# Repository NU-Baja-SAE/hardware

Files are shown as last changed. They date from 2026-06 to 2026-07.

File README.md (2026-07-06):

# NU Baja SAE — Hardware

KiCad schematics, PCB layouts, wiring harness designs, and BOM tooling for all NU Baja SAE electronics boards: the eCVT controller, the DAQ node, and the HUD node.

This guide assumes you have never used Git, GitHub, or KiCad before. Follow it top to bottom the first time; after that, skip to [Day-to-day workflow](#day-to-day-workflow).

## Table of contents

- [Glossary](#glossary)
- [One-time setup](#one-time-setup)
- [Getting the files onto your computer](#getting-the-files-onto-your-computer)
- [Opening a board in KiCad](#opening-a-board-in-kicad)
- [Day-to-day workflow](#day-to-day-workflow)
- [Structure](#structure)
- [Releases](#releases)
- [KiCad version](#kicad-version)

## Glossary

A few words you will see everywhere in this guide and on GitHub itself:

| Term | Meaning |
|---|---|
| Repository ("repo") | A folder of files (this one) tracked by Git, with full history of every change. |
| Git | The tool that tracks changes to files over time. Runs on your computer. |
| GitHub | The website that hosts a copy of the repo online so the team can share it. |
| Clone | Downloading a full copy of the repo (with its history) onto your computer. |
| Commit | A saved snapshot of your changes, with a short message describing what changed. |
| Push | Uploading your commits from your computer to GitHub. |
| Pull | Downloading other people's commits from GitHub to your computer. |
| Branch | An independent line of work, so you can make changes without touching `main` until they are ready. |
| Pull Request (PR) | A request to merge your branch into `main`, where others can review your changes before they land. |
| `main` | The default branch — the official, current state of the repo. |

## One-time setup

You only need to do this once per computer.

1. Create a GitHub account at [github.com](https://github.com) if you do not have one, and ask a team lead to add you to the `NU-Baja-SAE` organization so you have push access.
2. Install Git:
   - Windows: download and run the installer from [git-scm.com](https://git-scm.com/downloads). Default options are fine.
   - Mac: open Terminal and run `git --version` — macOS will offer to install it for you if it is missing.
3. Install GitHub Desktop (recommended if you are new to Git) from [desktop.github.com](https://desktop.github.com). It gives you a visual interface for the commit/push/pull steps below instead of typing commands. Everything in this guide can be done either with GitHub Desktop's buttons or with the `git` command line — both are described below.
4. Install KiCad — see [KiCad version](#kicad-version) below for which version to install. Download from [kicad.org/download](https://www.kicad.org/download/).
5. After cloning the repo (next section), add the shared parts library so connectors/ICs used across boards show up in KiCad — see [`libraries/README.md`](libraries/README.md).

## Getting the files onto your computer

This is called cloning the repo — it only needs to be done once per computer, after which you just "pull" updates.

Using GitHub Desktop:
1. Open GitHub Desktop and sign in with your GitHub account (File → Options → Accounts).
2. Click File → Clone Repository.
3. Choose the URL tab and paste: `https://github.com/NU-Baja-SAE/hardware`
4. Pick a local folder (e.g. `Documents/NU-Baja-SAE/hardware`) and click Clone.

Using the command line (Git Bash on Windows, Terminal on Mac):
```
git clone https://github.com/NU-Baja-SAE/hardware.git
cd hardware
```

Either way, you now have a folder called `hardware` on your computer containing everything in this repo.

## Opening a board in KiCad

Each board lives in its own folder under `boards/`, e.g. `boards/ecvt-controller/`. Inside that folder is a `.kicad_pro` file — this is the project file.

1. Open KiCad.
2. File → Open Project, then navigate to e.g. `hardware/boards/ecvt-controller/` and select the `.kicad_pro` file.
3. KiCad's project window shows the schematic (`.kicad_sch`) and PCB layout (`.kicad_pcb`) for that board — double-click either to open it in the schematic editor or PCB editor.
4. Make your edits and save (Ctrl+S / Cmd+S) as you normally would in KiCad. Saving only writes to your local copy of the files — it does not upload anything to GitHub. See the next section for how to share your changes.

If you are new to KiCad itself (not just this repo), the official [Getting Started guide](https://docs.kicad.org/) walks through schematic capture and PCB layout basics — worth a read before your first board edit.

## Day-to-day workflow

The general loop, every time you sit down to work on a board:

### 1. Pull the latest changes

Before you start editing, make sure you have everyone else's latest work, so you are not editing an outdated copy.

- GitHub Desktop: click Fetch origin, then Pull origin if it appears.
- Command line: `git pull`

### 2. Create a branch for your change

Do not edit `main` directly — work on a branch so your in-progress changes do not affect anyone else until they are reviewed.

- GitHub Desktop: click the branch dropdown (top middle) → New Branch. Name it something descriptive, e.g. `ecvt-add-current-sense`.
- Command line: `git checkout -b ecvt-add-current-sense`

### 3. Make your changes

Edit the KiCad files (schematic, PCB, etc.), or BOM/harness files, and save them as usual.

### 4. Commit your changes

A commit is a saved checkpoint with a message describing what you did. Commit often, in small logical chunks (e.g. "Add current sense resistor to eCVT controller" rather than one giant commit at the end).

- GitHub Desktop: the left panel lists every changed file. Check the ones you want to include, write a summary in the box at bottom-left, and click Commit to `<branch-name>`.
- Command line:
  ```
  git add boards/ecvt-controller/
  git commit -m "Add current sense resistor to eCVT controller"
  ```

### 5. Push your branch to GitHub

This uploads your commits so others (and CI, see below) can see them.

- GitHub Desktop: click Push origin.
- Command line: `git push -u origin ecvt-add-current-sense`

### 6. Open a Pull Request (PR)

A PR is how you propose merging your branch into `main`.

1. Go to [github.com/NU-Baja-SAE/hardware](https://github.com/NU-Baja-SAE/hardware) — GitHub usually shows a yellow banner offering to Compare & pull request for the branch you just pushed. Click it (or use GitHub Desktop's Create Pull Request button).
2. Write a short description of what changed and why.
3. Click Create pull request.
4. Automated checks (CI) will run against your PR — see `.github/workflows/ci.yml` for what gets checked (ERC/DRC, BOM diff, rendered schematic/PCB images, etc.). Wait for these to finish and fix anything they flag.
5. Ask a teammate to review. Once approved, click Merge pull request on GitHub.
6. Delete the branch (GitHub will prompt you) — its changes now live permanently in `main`.

### 7. Switch back to `main` and pull

- GitHub Desktop: switch the branch dropdown back to `main`, then Pull origin.
- Command line: `git checkout main && git pull`

You are back to a clean, up-to-date `main`, ready to start the loop again for your next change.

## Structure

```
hardware/
├── boards/
│   ├── ecvt-controller/   (.kicad_pro/.kicad_sch/.kicad_pcb + fab-outputs/ + README.md)
│   ├── daq-node/
│   └── hud-node/
├── harness/                # WireViz or WireLab YAML source + output/ (generated SVGs)
├── bom/
│   ├── consolidated-bom.csv
│   └── scripts/generate_bom.py
├── libraries/              # shared KiCad symbol/footprint libs
└── .github/workflows/
```

- `boards/<name>/` — one folder per physical board. Each contains its own KiCad project (`.kicad_pro`), schematic (`.kicad_sch`), PCB layout (`.kicad_pcb`), a `fab-outputs/` folder for generated gerbers/drill files/STEP models (not committed by hand — see below), and a short `README.md` describing the board.
- `harness/` — wiring harness definitions (WireViz/WireLab YAML), with rendered diagrams in `harness/output/`.
- `bom/` — the consolidated bill of materials across all boards (`consolidated-bom.csv`), generated automatically from the schematics by `bom/scripts/generate_bom.py`. Never edit the CSV by hand. If you change a schematic, run `python3 bom/scripts/generate_bom.py` and commit the updated CSV alongside your change — CI fails the PR if the committed CSV is out of date (and auto-regenerates it on direct pushes to `main` as a safety net).
- `libraries/` — shared KiCad symbol and footprint libraries used by more than one board, so parts stay consistent across designs.
- `.github/workflows/` — CI configuration; this is what automatically checks your PRs (see step 6 above).

Do not manually commit fab outputs (gerbers, drill files, `.step` files) — these are generated from the KiCad source files and are gitignored. CI regenerates them automatically on each PR.

## Releases

Board releases are tagged at the point gerbers are sent to fab, e.g. `ecvt-controller-v1.2`, with a one-line changelog per board.

## KiCad version

All board files must be authored/saved in the same KiCad version to avoid spurious diffs from format upgrades. Current standard version: **KiCad 9.0** — this is also the version CI runs (the `kicad/kicad:9.0` image in `.github/workflows/ci.yml`), so files saved in a newer major version will fail CI until both are bumped together.

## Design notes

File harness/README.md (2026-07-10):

# harness

The car's off-board wiring diagram — the wires that run **between** boards,
not the wiring internal to any one board. It is generated from the KiCad
board schematics on every push, so it can't drift out of sync with the boards.

## What's here

| Path | What it is |
|---|---|
| `car.yaml` | **Hand-maintained backbone.** The only file you edit by hand: it declares the battery/master-switch spine, the inter-board wires (CAN bus, power), and any junction boxes. It `includes:` the generated per-board connectors. |
| `generated/<board>.yaml` | **Build artifacts — never hand-edit.** One file per board listing that board's off-board connectors, extracted from its schematic. |
| `output/car.svg` | The rendered whole-car diagram. Regenerated + committed by CI. |
| `scripts/extract_connectors.py` | Extracts off-board connectors from each board's KiCad schematic (see `scripts/README.md`). |
| `scripts/test_pipeline.py` | Smoke test: extractor → build → idempotency. |
| `wirelab/` | Vendored copy of the YAML→SVG harness renderer (Wirelab). Build path needs `pydantic` + `PyYAML` (see `wirelab/requirements.txt`). |

## The pipeline

```
boards/<board>/*.kicad_sch
   │  extract_connectors.py  (kicad-cli netlist; keeps TE 917xxx + Molex 153110xx connectors)
   ▼
harness/generated/<board>.yaml
   │  included by
   ▼
harness/car.yaml  (hand-maintained backbone: battery, switch, inter-board wires)
   │  wirelab/cli.py build
   ▼
harness/output/car.svg
```

## Regenerate locally

Needs `kicad-cli` (KiCad 9) on PATH and the renderer's deps installed:

```
pip install -r harness/wirelab/requirements.txt
python3 harness/scripts/extract_connectors.py
python3 harness/wirelab/cli.py build harness/car.yaml -o harness/output/car.svg
```

Or just run the smoke test, which does the extract + build:

```
python3 harness/scripts/test_pipeline.py
```

## CI

The `harness-render` job (`.github/workflows/ci.yml`) runs in the
`kicad/kicad:9.0` container. On a **PR** it fails if the committed
`generated/*.yaml` or `output/car.svg` are stale (`extract_connectors.py
--check` + an SVG diff). On a **push to `main`** it regenerates and
auto-commits them (`[skip ci]`), the same safety-net pattern the consolidated
BOM job uses. So: change a board → push → the diagram updates itself.

Because CI rewrites `generated/*.yaml` and `output/car.svg` on every push to
`main`, their committed bytes are a moving target and two branches will almost
always differ there. To stop that from producing merge conflicts, those paths
are marked `merge=ours` in `.gitattributes` (git keeps one side instead of
conflicting; the next CI run regenerates the canonical copy). GitHub's merge
button honors this server-side. If you **merge or rebase locally**, register
the driver once so the attribute takes effect:

```
git config merge.ours.driver true
```

## Adding an inter-board wire / junction box

Edit `car.yaml`. Reference a board connector by its include alias and refdes,
e.g. `ecvt.J6.CANH`. Cross-board wires and the battery/switch spine live only
here; per-board connector pins come from `generated/` and update when the
board changes.

## Auxiliary boards & repeated (instanced) boards

Small aux boards (wheel/eCVT hall sensors, fuel sensor) follow the same
pattern as the big three: **one file per unique design**, instanced in
`car.yaml`.

- **A board that appears more than once on the car** (e.g. four identical
  wheel hall sensors) is still just ONE `generated/*.yaml`. Import it under
  several aliases in `car.yaml`'s `includes:` — `wheel_fl:`, `wheel_fr:`, … all
  pointing at `generated/wheel-hall.yaml`. Each alias becomes a separate copy
  of the connector in the diagram. The renderer namespaces each component's
  layout **zone by its include alias**, so every instance gets its own column
  (see `_resolve_includes` in `wirelab/parser.py`). Wire each instance
  independently, e.g. `daq.J7.LEFT_HALL -> wheel_fl.J1.HALL_OUT`.

- **A real KiCad board** goes in `boards/<name>/` and its `generated/<name>.yaml`
  is produced by `extract_connectors.py` like any other board.

- **A placeholder board** (design not drawn yet) can be a hand-written
  `generated/<name>.yaml` with a `# HAND-WRITTEN PLACEHOLDER` header. Because
  the extractor only writes/`--check`s files for folders that exist under
  `boards/`, a placeholder with no matching board folder is left untouched by
  CI. When you later add `boards/<name>/`, the extractor regenerates that file
  and it becomes a normal build artifact — the hand file is transparently
  replaced. (Keep the placeholder's connectors/pins matching the intended
  design so the diagram stays truthful until the real board lands.)

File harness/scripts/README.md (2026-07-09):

# harness/scripts

## `extract_connectors.py`

Generates `harness/generated/<board>.yaml` — one file per board describing
that board's **off-board** connectors (the pins whose wires leave the board
and become part of the car harness). Board-internal nets are ignored.

It runs `kicad-cli sch export netlist` on each board's root schematic, keeps
only the harness connector families (TE 917xxx, Molex 15311026/15311046), and
writes a pin-per-connector-pin YAML with each pin named by the net on it.

```
python3 harness/scripts/extract_connectors.py          # regenerate generated/*.yaml
python3 harness/scripts/extract_connectors.py --check   # exit 1 if any file is stale (CI)
```

Requires `kicad-cli` (KiCad 9) on PATH. Symbols resolve from each schematic's
embedded cache, so no library table / `BAJA_LIB` env var is needed — it runs
the same on a laptop and in the CI `kicad/kicad:9.0` container.

### Files under `harness/generated/` are BUILD ARTIFACTS

Never hand-edit them. To change a connector, edit the board schematic and
regenerate. CI runs `--check` on every PR; if it fails, regenerate and commit.

### The pipeline

```
boards/<board>/*.kicad_sch
        │  extract_connectors.py (kicad-cli netlist)
        ▼
harness/generated/<board>.yaml        (one connector component per J-ref)
        │  included by
        ▼
harness/car.yaml   (hand-maintained backbone: joins boards, junction boxes,
        │           inter-board wires)
        ▼  wireviz_alternative build
harness/output/car.svg                (the whole-car off-board wiring diagram)
```

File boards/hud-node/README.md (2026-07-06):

# hud-node

KiCad project for the HUD node board. Add `.kicad_pro`/`.kicad_sch`/`.kicad_pcb` files here, with generated fab outputs under `fab-outputs/` (gitignored).

<!-- CI trigger test -->

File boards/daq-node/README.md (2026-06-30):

# daq-node

KiCad project for the DAQ node board. Add `.kicad_pro`/`.kicad_sch`/`.kicad_pcb` files here, with generated fab outputs under `fab-outputs/` (gitignored).

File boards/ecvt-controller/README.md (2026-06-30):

# ecvt-controller

KiCad project for the eCVT controller board. Add `.kicad_pro`/`.kicad_sch`/`.kicad_pcb` files here, with generated fab outputs under `fab-outputs/` (gitignored).

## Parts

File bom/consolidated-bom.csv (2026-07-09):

part_number | description | manufacturer | quantity | board | notes
0.1 µF 0603 | Unpolarized capacitor |  | 1 | daq-node | C11
0.1 µF 0603 | Unpolarized capacitor, small symbol |  | 1 | daq-node | C5
0.1 µF 0805 | Unpolarized capacitor |  | 3 | daq-node | C2 C4 C6
15311026 |  |  | 1 | daq-node | J5
1k 0603 | Resistor |  | 1 | daq-node | R3
220 pF 0603 | Unpolarized capacitor |  | 2 | daq-node | C19 C20
4.7µF 0603 | Unpolarized capacitor |  | 3 | daq-node | C1 C3 C12
5V | Zener diode |  | 1 | daq-node | D2
917780-1 |  |  | 1 | daq-node | J8
917781-1 |  |  | 1 | daq-node | J4
917783-1 |  | TE | 1 | daq-node | J7
917784-1 |  |  | 1 | daq-node | J1
ACT45B-101-2P-TL003 |  |  | 1 | daq-node | U5
Conn_01x19_Socket | Generic connector, single row, 01x19, script generated |  | 2 | daq-node | J11 J12
DF2S5M4CTL3FCT-ND | Zener diode |  | 4 | daq-node | D3 D4 D5 D6
DM3CS-SF |  | Hirose | 1 | daq-node | J6
Fuse 0603 | Fuse |  | 1 | daq-node | F1
Q_PMOS_DGS | P-MOSFET transistor, drain/gate/source |  | 1 | daq-node | Q1
SMAJ26A | 400W unidirectional Transient Voltage Suppressor, 26.0Vr, SMA(DO-214AC) |  | 1 | daq-node | D1
TJA1051T-3 | High-Speed CAN Transceiver, separate VIO, silent mode, SOIC-8 |  | 1 | daq-node | U2
TPD2EUSB30 | 2-Channel ESD Protection for Super-Speed USB 3.0 Interface, DRT-3 |  | 1 | daq-node | U4
TSR_1-2450 | 1A step-down regulator module, fixed 5V output voltage, 5-36V input voltage, -40°C to +85°C temperature range, TO-220 compatible LM78xx replacement |  | 1 | daq-node | U3
0.01µF 0603 | Unpolarized capacitor, small symbol |  | 3 | ecvt-controller | C1 C3 C5
0.1 µF 0603 | Unpolarized capacitor |  | 6 | ecvt-controller | C10 C11 C13 C15 C17 C18
0.1 µF 0603 | Unpolarized capacitor, small symbol |  | 3 | ecvt-controller | C6 C8 C9
100µF | Polarized capacitor, small symbol |  | 1 | ecvt-controller | C2
10k 0603 | Resistor |  | 2 | ecvt-controller | R6 R7
10kΩ 0603 | Resistor, small US symbol |  | 2 | ecvt-controller | R1 R2
15311026 |  |  | 1 | ecvt-controller | J4
15311046 |  |  | 1 | ecvt-controller | J2
1k 0603 | Resistor |  | 1 | ecvt-controller | R3
1µF 0603 | Unpolarized capacitor, small symbol |  | 2 | ecvt-controller | C4 C7
220 pF 0603 | Unpolarized capacitor |  | 2 | ecvt-controller | C19 C20
4.7µF 0603 | Unpolarized capacitor |  | 3 | ecvt-controller | C12 C14 C16
5V | Zener diode |  | 1 | ecvt-controller | D4
60 1206 | Resistor |  | 2 | ecvt-controller | R4 R5
917780-1 |  |  | 1 | ecvt-controller | J6
917781-1 |  |  | 1 | ecvt-controller | J10
917782-1 |  |  | 1 | ecvt-controller | J1
917784-1 |  |  | 1 | ecvt-controller | J3
917786-1 |  |  | 1 | ecvt-controller | J5
ACT45B-101-2P-TL003 |  |  | 1 | ecvt-controller | U5
Conn_01x19_Socket | Generic connector, single row, 01x19, script generated |  | 2 | ecvt-controller | J8 J9
ESD3V3AP-TP |  |  | 3 | ecvt-controller | U2 U6 U7
Fuse 0603 | Fuse |  | 1 | ecvt-controller | F1
LED | Light emitting diode |  | 2 | ecvt-controller | D2 D6
Q_PMOS_DGS | P-MOSFET transistor, drain/gate/source |  | 1 | ecvt-controller | Q1
S23LC03 |  |  | 1 | ecvt-controller | U8
SMAJ26A | 400W unidirectional Transient Voltage Suppressor, 26.0Vr, SMA(DO-214AC) |  | 1 | ecvt-controller | D5
TI DRV8462DDVR | 65 V, 5-10 A Stepper Motor Driver for High Efficiency and Noiseless Operation |  | 1 | ecvt-controller | U1
TJA1051T-3 | High-Speed CAN Transceiver, separate VIO, silent mode, SOIC-8 |  | 1 | ecvt-controller | U4
TSR_1-2450 | 1A step-down regulator module, fixed 5V output voltage, 5-36V input voltage, -40°C to +85°C temperature range, TO-220 compatible LM78xx replacement |  | 1 | ecvt-controller | U3
.01u 0805 | Unpolarized capacitor |  | 2 | hud-node | C1 C2
.1uF 0603 | Unpolarized capacitor |  | 1 | hud-node | C6
.1uf 0805 | Unpolarized capacitor |  | 1 | hud-node | C7
0603 Fuse 0603 | Fuse |  | 1 | hud-node | F1
100 0603 | Resistor |  | 1 | hud-node | R4
1k 0603 | Resistor |  | 1 | hud-node | R3
220p 0603 | Unpolarized capacitor |  | 2 | hud-node | C4 C5
4.7u 0603 | Polarized capacitor |  | 1 | hud-node | C3
5V | Zener diode |  | 1 | hud-node | D1
60 1206 | Resistor |  | 2 | hud-node | R1 R2
917780-1 |  |  | 2 | hud-node | J3 J4
917781-1 |  |  | 1 | hud-node | J6
ACT45B-101-2P-TL003 |  |  | 1 | hud-node | U3
Conn_01x04 | Generic connector, single row, 01x04, script generated (kicad-library-utils/schlib/autogen/connector/) |  | 1 | hud-node | J5
Conn_01x19_Socket | Generic connector, single row, 01x19, script generated |  | 2 | hud-node | J1 J2
Q_PMOS_DGS | P-MOSFET transistor, drain/gate/source |  | 1 | hud-node | Q1
R_Potentiometer | Potentiometer |  | 1 | hud-node | RV1
SMAJ26A | 400W unidirectional Transient Voltage Suppressor, 26.0Vr, SMA(DO-214AC) |  | 1 | hud-node | D2
TJA1051T-3 | High-Speed CAN Transceiver, separate VIO, silent mode, SOIC-8 |  | 1 | hud-node | U2
TPD2EUSB30 | 2-Channel ESD Protection for Super-Speed USB 3.0 Interface, DRT-3 |  | 1 | hud-node | U5
TSR_1-2450 | 1A step-down regulator module, fixed 5V output voltage, 5-36V input voltage, -40°C to +85°C temperature range, TO-220 compatible LM78xx replacement |  | 1 | hud-node | U1
~ | 4.7 inch 240x128 Dots Graphic LCD Module |  | 1 | hud-node | U4

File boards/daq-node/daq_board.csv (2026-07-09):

Reference | Qty | Value | DNP | Exclude from BOM | Exclude from Board | Footprint | Datasheet
C1,C3 | 2 | 4.7µF |  |  |  | Capacitor_SMD:C_0603_1608Metric_Pad1.08x0.95mm_HandSolder | ~
C2,C4,C6 | 3 | 0.1 µF |  |  |  | Capacitor_SMD:C_0805_2012Metric_Pad1.18x1.45mm_HandSolder | ~
C5,C18 | 2 | 0.1 µF |  |  |  | Capacitor_SMD:C_0603_1608Metric_Pad1.08x0.95mm_HandSolder | ~
C19,C20 | 2 | 220 pF |  |  |  | Capacitor_SMD:C_0603_1608Metric_Pad1.08x0.95mm_HandSolder | ~
D1 | 1 | SMAJ26A |  |  |  | Diode_SMD:D_SMA | https://www.littelfuse.com/media?itemid=75e32973-b177-4ee3-a0ff-cedaf1abdb93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
D2 | 1 | 5V |  |  |  | Diode_SMD:D_SMA | ~
J1,J2,J3,J4,J5,J6,J7 | 7 | 917781-1 |  |  |  | Connector_1x3:CON3_1X3_P100 | https://www.te.com/commerce/DocumentDelivery/DDEController?Action=srchrtrv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
J8,J9 | 2 | 917780-1 |  |  |  | Connector_1x2:CON2_1X2_P100 | https://www.te.com/commerce/DocumentDelivery/DDEController?Action=srchrtrv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
J10 | 1 | Conn_01x09_Socket |  |  |  | Connector_PinHeader_2.54mm:PinHeader_1x09_P2.54mm_Vertical | ~
J11,J12 | 2 | Conn_01x19_Socket |  |  |  | Connector_PinHeader_2.54mm:PinHeader_1x19_P2.54mm_Vertical | ~
Q1 | 1 | Q_PMOS_DGS |  |  |  | Package_TO_SOT_SMD:SOT-23-3 | ~
R1,R2 | 2 | 60 |  |  |  | Resistor_SMD:R_0603_1608Metric_Pad0.98x0.95mm_HandSolder | ~
R3 | 1 | 1k |  |  |  | Resistor_SMD:R_0603_1608Metric_Pad0.98x0.95mm_HandSolder | ~
U2 | 1 | TJA1051T-3 |  |  |  | Package_SO:SOIC-8_3.9x4.9mm_P1.27mm | http://www.nxp.com/docs/en/data-sheet/TJA1051.pdf
U3 | 1 | TSR_1-2450 |  |  |  | Converter_DCDC:Converter_DCDC_TRACO_TSR-1_THT | http://www.tracopower.com/products/tsr1.pdf
U4 | 1 | TPD2EUSB30 |  |  |  | Package_TO_SOT_SMD:Texas_DRT-3 | http://www.ti.com/lit/ds/symlink/tpd2eusb30a.pdf
U5 | 1 | ACT45B-101-2P-TL003 |  |  |  | baja_footprint_library:ACT45B-101-2P-TL003

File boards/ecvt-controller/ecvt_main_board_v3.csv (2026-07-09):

Reference | Qty | Value | DNP | Exclude from BOM | Exclude from Board | Footprint | Datasheet
C1,C3,C5 | 3 | 0.01µF |  |  |  | Capacitor_SMD:C_0603_1608Metric_Pad1.08x0.95mm_HandSolder | ~
C2 | 1 | 100µF |  |  |  | Capacitor_SMD:CP_Elec_10x10.5 | ~
C4,C7 | 2 | 1µF |  |  |  | Capacitor_SMD:C_0603_1608Metric_Pad1.08x0.95mm_HandSolder | ~
C6,C8,C9 | 3 | 0.1 µF |  |  |  | Capacitor_SMD:C_0603_1608Metric_Pad1.08x0.95mm_HandSolder | ~
C10,C11,C13,C15,C17,C18 | 6 | 0.1 µF |  |  |  | Capacitor_SMD:C_0805_2012Metric_Pad1.18x1.45mm_HandSolder | ~
C12,C14,C16 | 3 | 4.7µF |  |  |  | Capacitor_SMD:C_0603_1608Metric_Pad1.08x0.95mm_HandSolder | ~
C19,C20 | 2 | 220 pF |  |  |  | Capacitor_SMD:C_0603_1608Metric_Pad1.08x0.95mm_HandSolder | ~
D1,D3 | 2 | DF2S5M4CTL3FCT-ND |  |  |  | Diode_SMD:D_SOD-882 | ~
D2,D6 | 2 | LED |  |  |  | LED_SMD:LED_Luminus_MP-3030-1100_3.0x3.0mm | ~
D4 | 1 | 5V |  |  |  | Diode_SMD:D_SMA | ~
D5 | 1 | SMAJ26A |  |  |  | Diode_SMD:D_SMA | https://www.littelfuse.com/media?itemid=75e32973-b177-4ee3-a0ff-cedaf1abdb93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
F1 | 1 | Fuse |  |  |  | Fuse:Fuse_0603_1608Metric_Pad1.05x0.95mm_HandSolder | ~
H1,H2,H3,H4 | 4 | MountingHole |  | Excluded from BOM |  | MountingHole:MountingHole_3.2mm_M3 | ~
J1 | 1 | 917782-1 |  |  |  | baja_footprint_library:TE-Connectivity_917782 | https://www.te.com/commerce/DocumentDelivery/DDEController?Action=srchrtrv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
J2 | 1 | 15311046 |  |  |  | baja_footprint_library:MOLEX_15311046 | https://www.molex.com/en-us/products/part-detail-pdf/15311046?display=pdf
J3 | 1 | 917791-1 |  |  |  | baja_footprint_library:TE-Connectivity_917791
J4 | 1 | 15311026 |  |  |  | baja_footprint_library:MOLEX_15311026 | https://www.molex.com/en-us/products/part-detail-pdf/15311026?display=pdf
J6 | 1 | 917780-1 |  |  |  | baja_footprint_library:TE-Connectivity_ 917780 | https://www.te.com/commerce/DocumentDelivery/DDEController?Action=srchrtrv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
J8,J9 | 2 | Conn_01x19_Socket |  |  |  | Connector_PinSocket_2.54mm:PinSocket_1x19_P2.54mm_Vertical | ~
J10 | 1 | 917781-1 |  |  |  | baja_footprint_library:TE-Connectivity_917781 | https://www.te.com/commerce/DocumentDelivery/DDEController?Action=srchrtrv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
Q1 | 1 | Q_PMOS_DGS |  |  |  | Package_TO_SOT_SMD:SOT-23-3 | ~
R1,R2 | 2 | 10kΩ |  |  |  | Resistor_SMD:R_0603_1608Metric_Pad0.98x0.95mm_HandSolder | ~
R3 | 1 | 1k |  |  |  | Resistor_SMD:R_0603_1608Metric_Pad0.98x0.95mm_HandSolder | ~
R4,R5 | 2 | 60 |  |  |  | Resistor_SMD:R_0603_1608Metric_Pad0.98x0.95mm_HandSolder | ~
R6,R7 | 2 | 100k |  |  |  | Resistor_SMD:R_0603_1608Metric_Pad0.98x0.95mm_HandSolder | ~
U1 | 1 | TI DRV8462DDVR |  |  |  | Package_SO:HTSSOP-44_6.1x14mm_P0.635mm_TopEP4.14x7.01mm | kicad-embed://Motor Driver 10A (drv8462).pdf
U2,U6 | 2 | TPD2EUSB30 |  |  |  | Package_TO_SOT_SMD:Texas_DRT-3 | http://www.ti.com/lit/ds/symlink/tpd2eusb30a.pdf
U3 | 1 | TSR_1-2450 |  |  |  | Converter_DCDC:Converter_DCDC_TRACO_TSR-1_THT | http://www.tracopower.com/products/tsr1.pdf
U4 | 1 | TJA1051T-3 |  |  |  | Package_SO:SOIC-8_3.9x4.9mm_P1.27mm | http://www.nxp.com/docs/en/data-sheet/TJA1051.pdf
U5 | 1 | ACT45B-101-2P-TL003 |  |  |  | baja_footprint_library:ACT45B-101-2P-TL003

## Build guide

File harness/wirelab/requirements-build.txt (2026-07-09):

# Dependencies for the BUILD path only (extract + build the diagram in CI).
# The interactive `serve` editor additionally needs ruamel.yaml (see
# requirements.txt), but CI never runs the editor.
pydantic>=2
PyYAML>=6

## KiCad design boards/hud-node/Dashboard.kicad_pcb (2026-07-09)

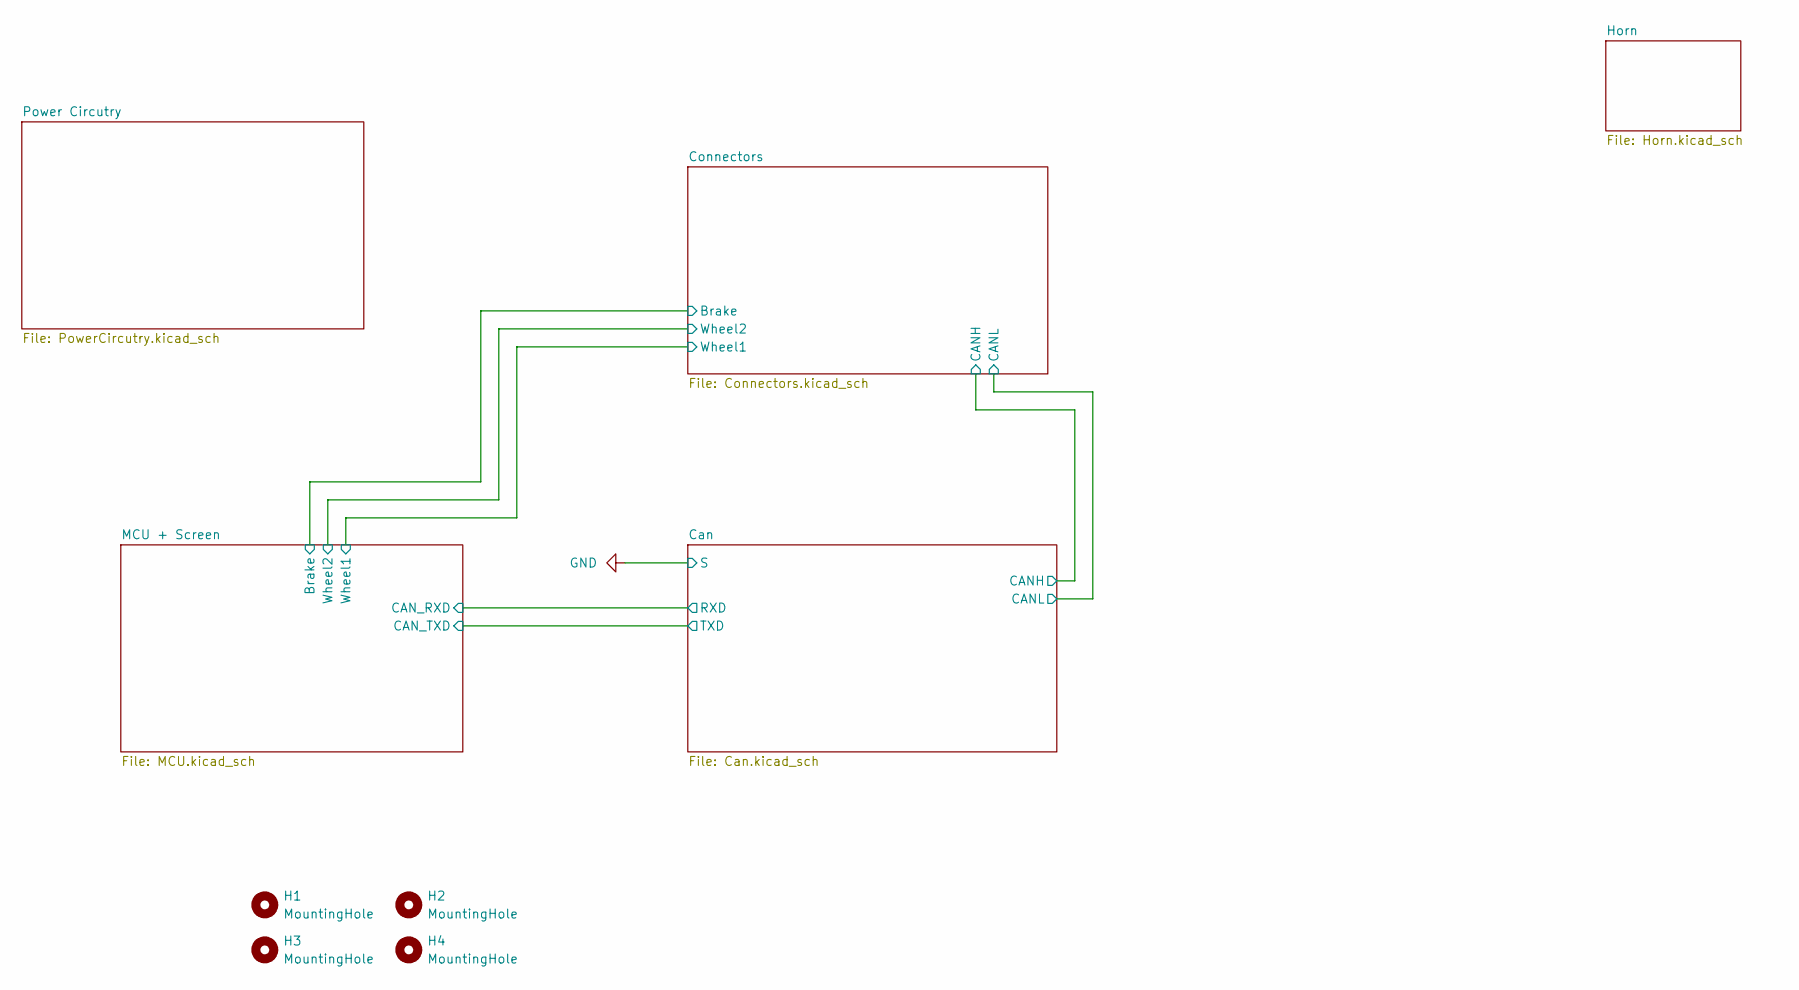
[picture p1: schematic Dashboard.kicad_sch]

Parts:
H1, H2, H3, H4: MountingHole; MountingHole_3.2mm_M3

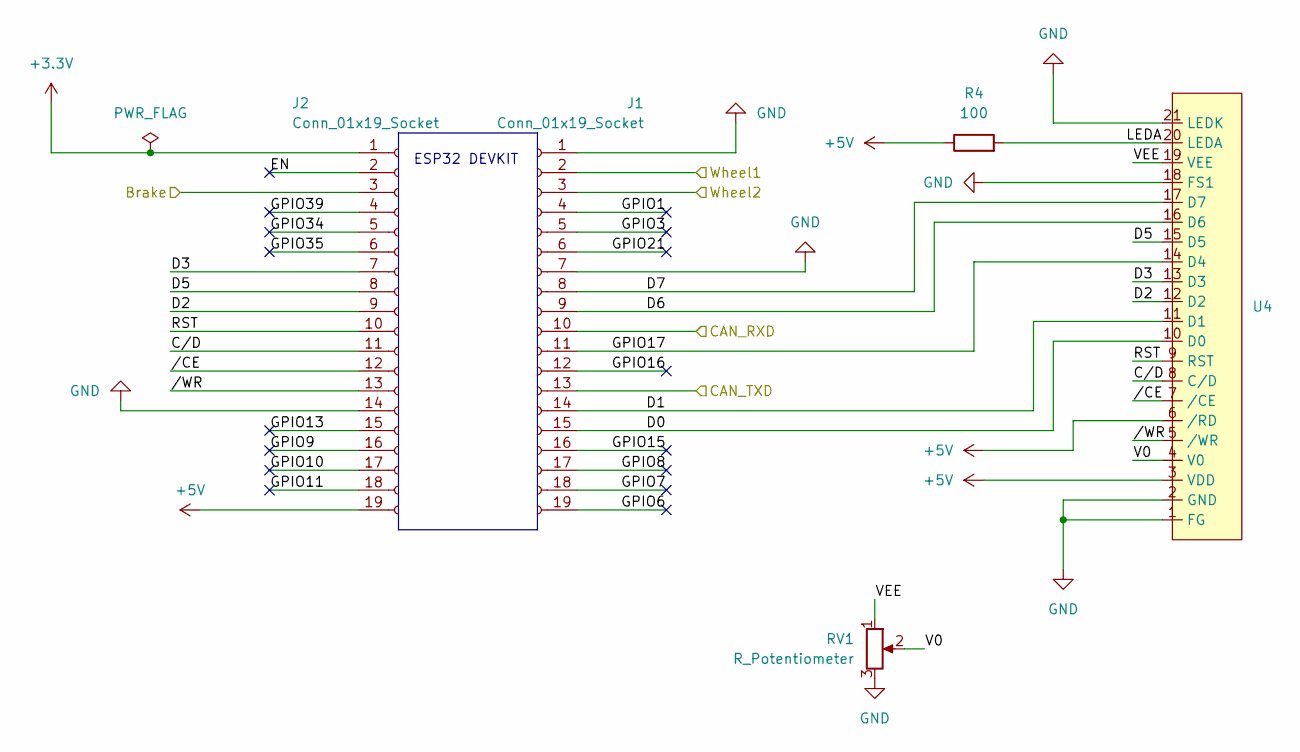
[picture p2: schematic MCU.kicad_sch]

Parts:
J1, J2: Conn_01x19_Socket; PinSocket_1x19_P2.54mm_Vertical
R4: 100; R_0603_1608Metric_Pad0.98x0.95mm_HandSolder
RV1: R_Potentiometer; Potentiometer_Bourns_3386F_Vertical
U4: PinHeader_1x21_P2.54mm_Vertical

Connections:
+3.3V: J2.1; also elsewhere on the board
+5V: J2.19, R4.1, U4.3 (VDD), U4.6 (/RD); also elsewhere on the board
/Can/RXD: J1.13; also elsewhere on the board
/Can/TXD: J1.10; also elsewhere on the board
/Connectors/Brake: J2.3; also elsewhere on the board
/Connectors/Wheel1: J1.2; also elsewhere on the board
/Connectors/Wheel2: J1.3; also elsewhere on the board
/MCU + Screen/C/D: J2.11, U4.8 (C/D)
/MCU + Screen/D0: J1.15, U4.10 (D0)
/MCU + Screen/D1: J1.14, U4.11 (D1)
/MCU + Screen/D3: J2.7, U4.13 (D3)
/MCU + Screen/D5: J2.8, U4.15 (D5)
/MCU + Screen/D6: J1.9, U4.16 (D6)
/MCU + Screen/D7: J1.8, U4.17 (D7)
/MCU + Screen/EN: J2.2
/MCU + Screen/GPIO1: J1.4
/MCU + Screen/GPIO3: J1.5
/MCU + Screen/GPIO6: J1.19
/MCU + Screen/GPIO7: J1.18
/MCU + Screen/GPIO8: J1.17
/MCU + Screen/GPIO9: J2.16
/MCU + Screen/GPIO10: J2.17
/MCU + Screen/GPIO11: J2.18
/MCU + Screen/GPIO13: J2.15
/MCU + Screen/GPIO15: J1.16
/MCU + Screen/GPIO16: J1.12
/MCU + Screen/GPIO17: J1.11, U4.14 (D4)
/MCU + Screen/GPIO21: J1.6
/MCU + Screen/GPIO34: J2.5
/MCU + Screen/GPIO39: J2.4
/MCU + Screen/LEDA: R4.2, U4.20 (LEDA)
/MCU + Screen/RST: J2.10, U4.9 (RST)
/MCU + Screen/V0: RV1.2, U4.4 (V0)
/MCU + Screen/VEE: RV1.1, U4.19 (VEE)
/MCU + Screen//CE: J2.12, U4.7 (/CE)
/MCU + Screen//WR: J2.13, U4.5 (/WR)
GND: J1.1, J1.7, J2.14, RV1.3, U4.1 (FG), U4.2 (GND), U4.18 (FS1), U4.21 (LEDK); also elsewhere on the board

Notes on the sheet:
ESP32 DEVKIT

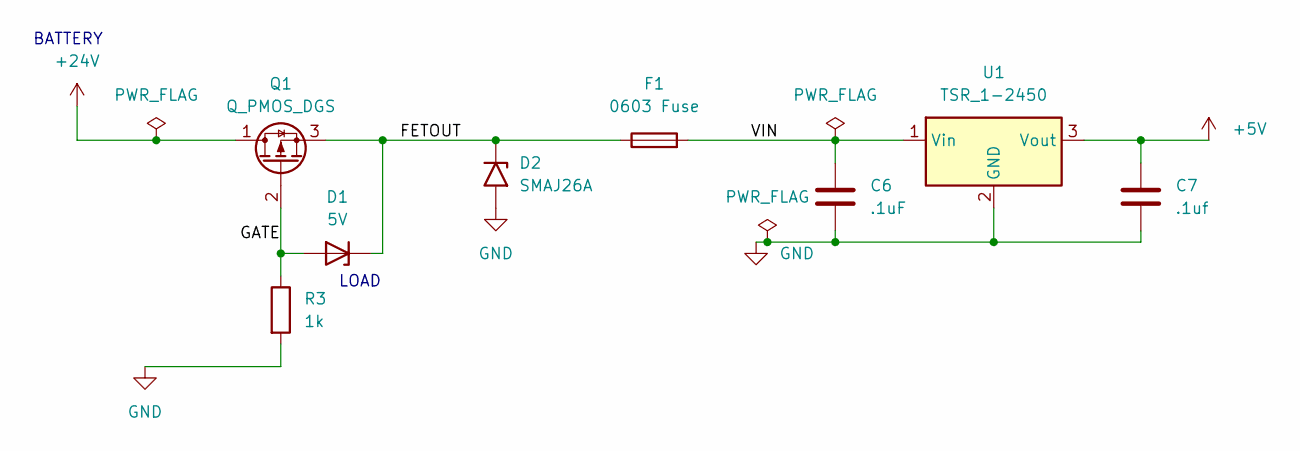
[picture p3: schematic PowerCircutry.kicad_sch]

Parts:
C6: .1uF; C_0603_1608Metric_Pad1.08x0.95mm_HandSolder
C7: .1uf; C_0805_2012Metric_Pad1.18x1.45mm_HandSolder
D1: 5V; D_SMA
D2: SMAJ26A; D_SMA
F1: 0603 Fuse; Fuse_0603_1608Metric_Pad1.05x0.95mm_HandSolder
Q1: Q_PMOS_DGS; SOT-23-3
R3: 1k; R_0603_1608Metric_Pad0.98x0.95mm_HandSolder
U1: TSR_1-2450; Converter_DCDC_TRACO_TSR-1_THT

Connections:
+5V: C7.1, U1.3 (Vout); also elsewhere on the board
+24V: Q1.1 (D); also elsewhere on the board
/Power Circutry/FETOUT: D1.1 (K), D2.1 (A1), F1.1, Q1.3 (S)
/Power Circutry/GATE: D1.2 (A), Q1.2 (G), R3.1
/Power Circutry/VIN: C6.1, F1.2, U1.1 (Vin)
GND: C6.2, C7.2, D2.2 (A2), R3.2, U1.2 (GND); also elsewhere on the board

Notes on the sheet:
LOAD
BATTERY

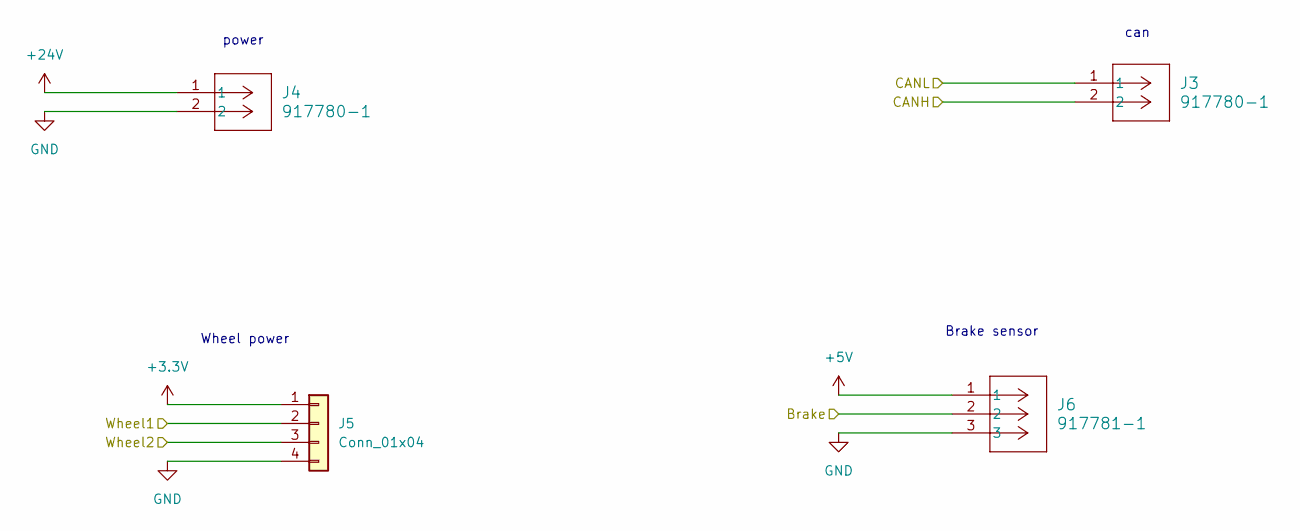
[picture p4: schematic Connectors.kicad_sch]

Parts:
J3, J4: 917780-1; TE-Connectivity_ 917780
J5: Conn_01x04; TE-Connectivity_917782
J6: 917781-1; TE-Connectivity_917781

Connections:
+3.3V: J5.1; also elsewhere on the board
+5V: J6.1; also elsewhere on the board
+24V: J4.1; also elsewhere on the board
/Can/CANH: J3.2; also elsewhere on the board
/Can/CANL: J3.1; also elsewhere on the board
/Connectors/Brake: J6.2; also elsewhere on the board
/Connectors/Wheel1: J5.2; also elsewhere on the board
/Connectors/Wheel2: J5.3; also elsewhere on the board
GND: J4.2, J5.4, J6.3; also elsewhere on the board

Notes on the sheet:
power
Brake sensor
Wheel power
can

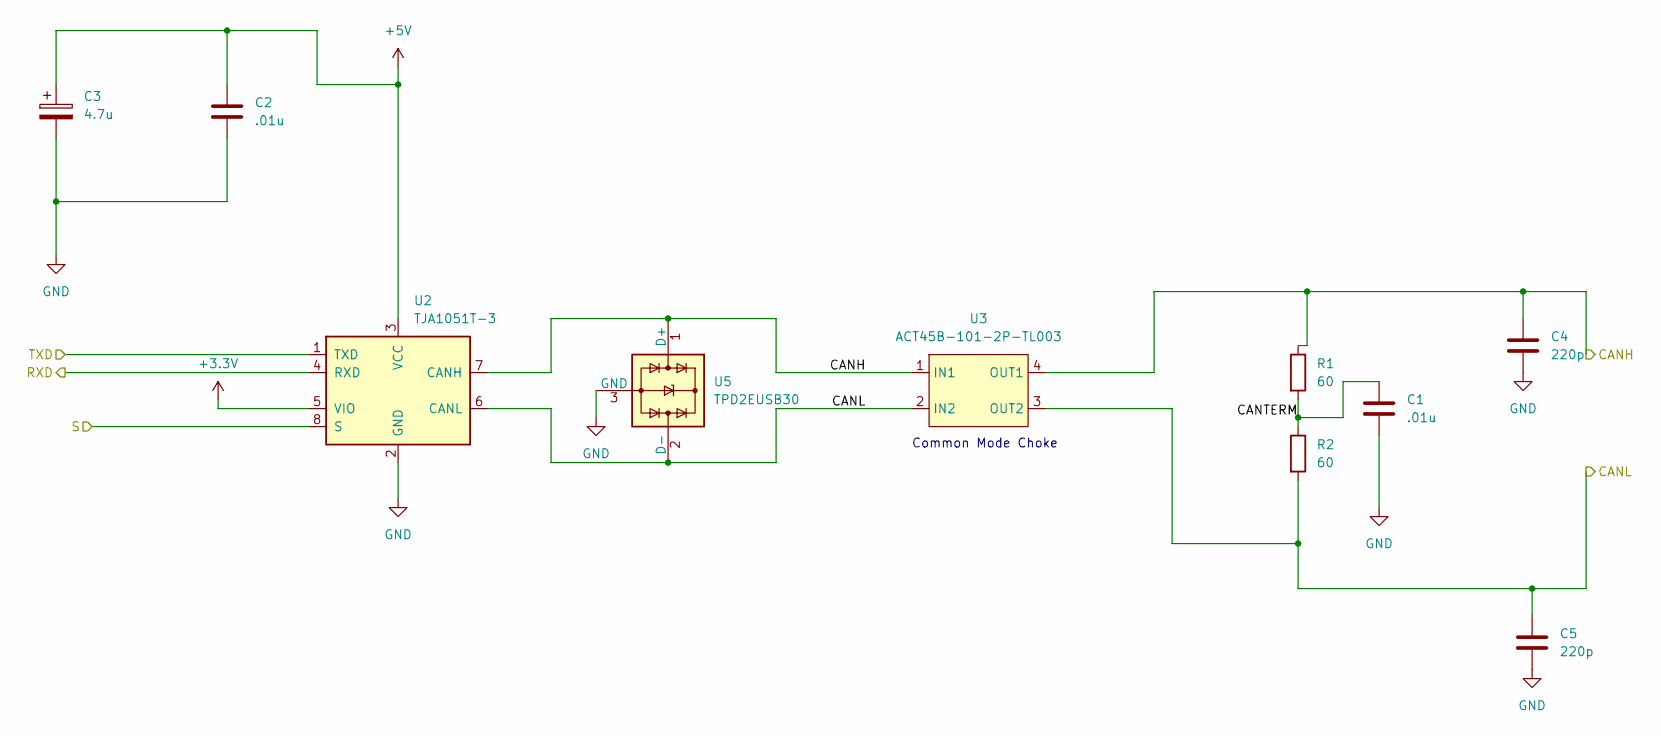
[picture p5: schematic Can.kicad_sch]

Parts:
C1, C2: .01u; C_0805_2012Metric_Pad1.18x1.45mm_HandSolder
C3: 4.7u; C_0603_1608Metric_Pad1.08x0.95mm_HandSolder
C4, C5: 220p; C_0603_1608Metric_Pad1.08x0.95mm_HandSolder
R1, R2: 60; R_1206_3216Metric_Pad1.30x1.75mm_HandSolder
U2: TJA1051T-3; SOIC-8_3.9x4.9mm_P1.27mm
U3: ACT45B-101-2P-TL003
U5: TPD2EUSB30; Texas_DRT-3

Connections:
+3.3V: U2.5 (VIO); also elsewhere on the board
+5V: C2.1, C3.1, U2.3 (VCC); also elsewhere on the board
/Can/CANH: C4.1, R1.1, U2.7 (CANH), U3.1 (IN1), U3.4 (OUT1), U5.1 (D+); also elsewhere on the board
/Can/CANL: C5.1, R2.2, U2.6 (CANL), U3.2 (IN2), U3.3 (OUT2), U5.2 (D-); also elsewhere on the board
/Can/CANTERM: C1.1, R1.2, R2.1
/Can/RXD: U2.4 (RXD); also elsewhere on the board
/Can/TXD: U2.1 (TXD); also elsewhere on the board
GND: C1.2, C2.2, C3.2, C4.2, C5.2, U2.2 (GND), U2.8 (S), U5.3 (GND); also elsewhere on the board

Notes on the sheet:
Common Mode Choke

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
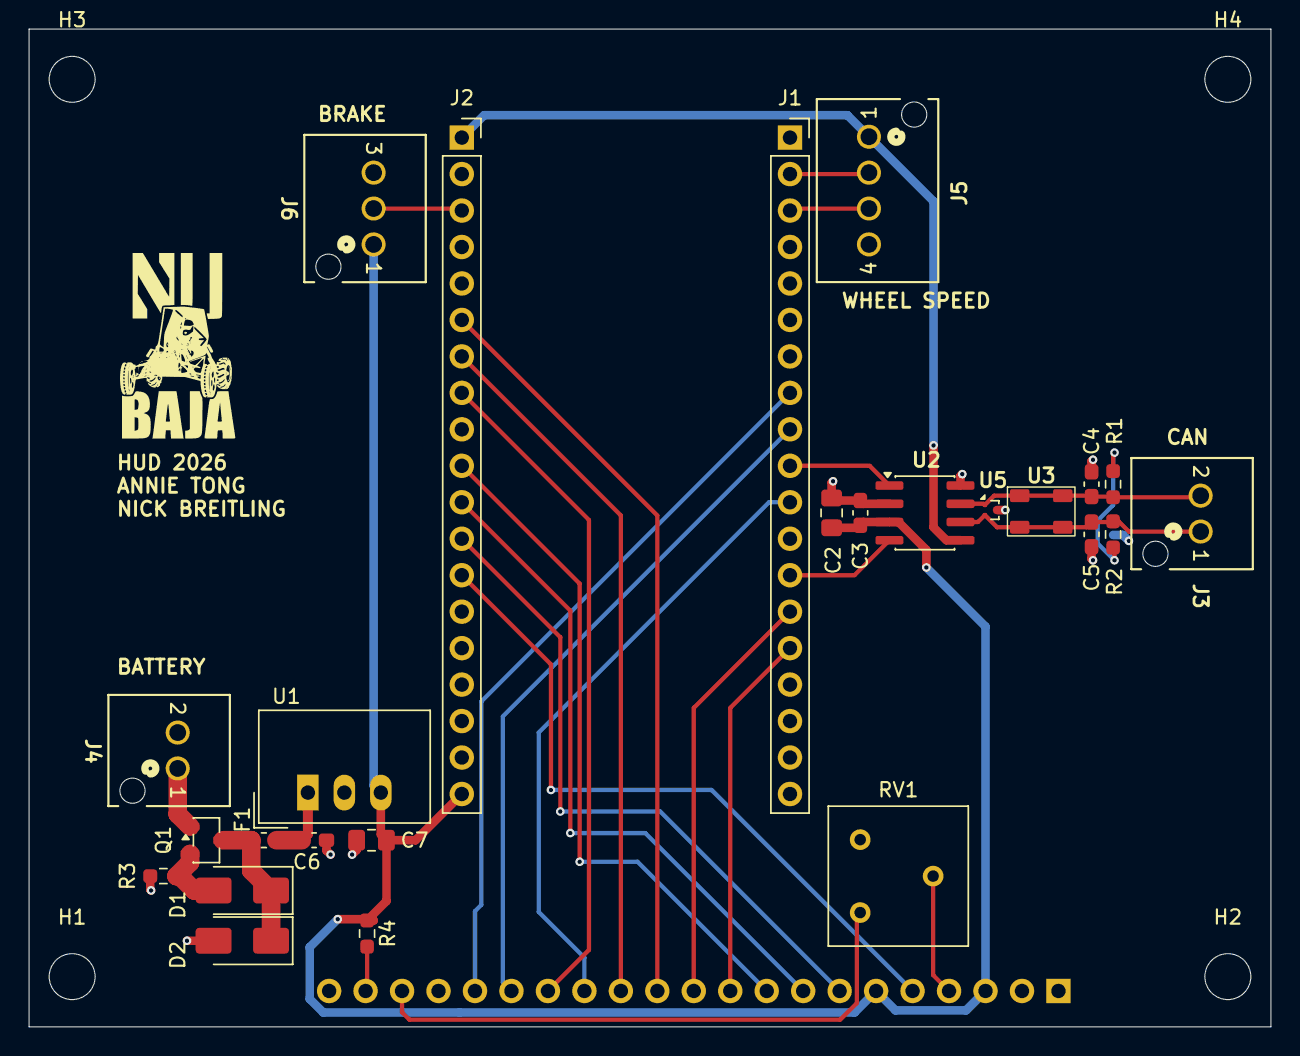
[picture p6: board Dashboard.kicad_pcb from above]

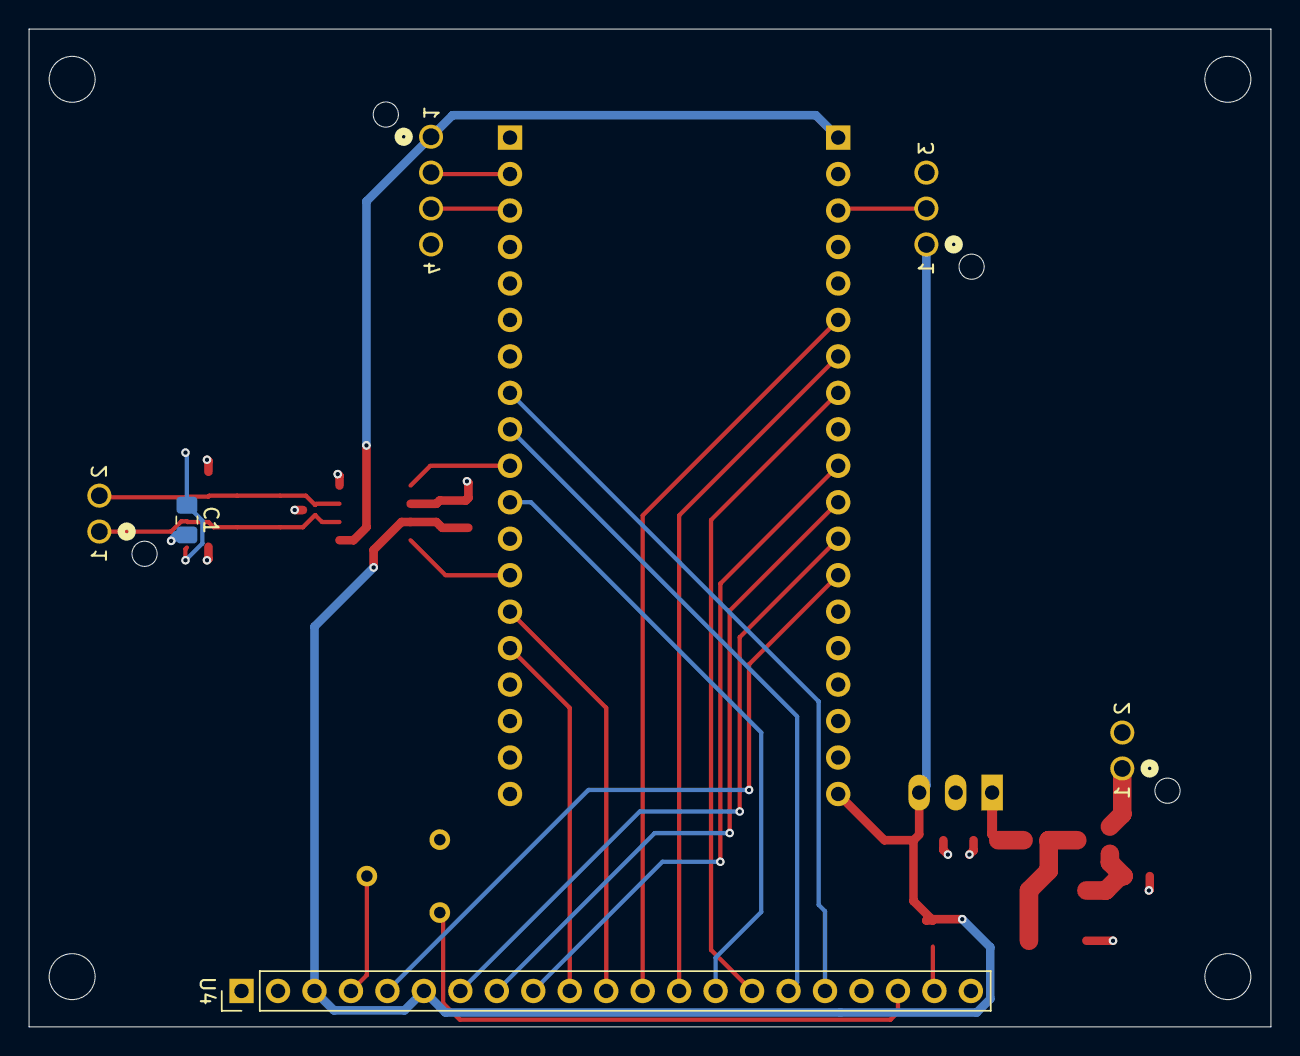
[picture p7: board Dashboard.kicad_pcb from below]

Board: 4 copper layers, 86.5 x 69.5 mm, 31 parts (2 on the bottom side), 30 nets.

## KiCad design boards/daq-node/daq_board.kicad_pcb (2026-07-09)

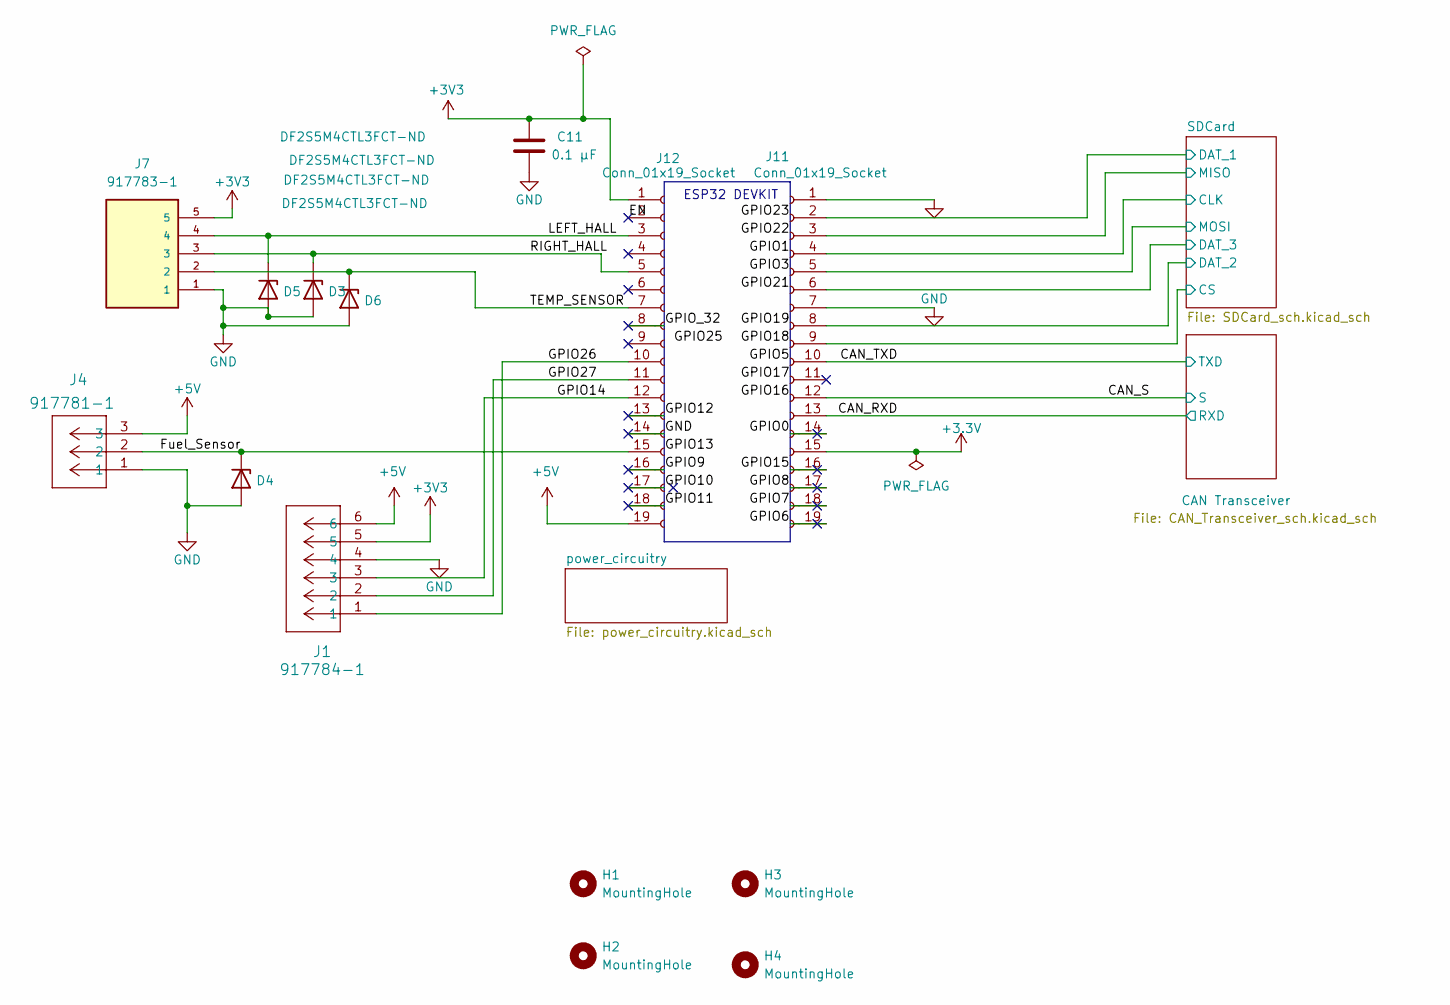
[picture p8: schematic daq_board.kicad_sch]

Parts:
C11: 0.1 µF; C_0603_1608Metric_Pad1.08x0.95mm_HandSolder
D3, D4, D5, D6: DF2S5M4CTL3FCT-ND; D_SOD-882
H1, H2, H3, H4: MountingHole; MountingHole_3.2mm_M3
J1: 917784-1; TE-Connectivity_1x6
J4: 917781-1; CON3_1X3_P100
J7: 917783-1; Connector_1x5; PARTREV R
J11, J12: Conn_01x19_Socket; PinSocket_1x19_P2.54mm_Vertical

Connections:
+3.3V: J11.15; also elsewhere on the board
+3V3: C11.1, J1.5, J7.5, J12.1; also elsewhere on the board
+5V: J1.6, J4.3, J12.19; also elsewhere on the board
/CAN_RXD: J11.13; also elsewhere on the board
/CAN_S: J11.12; also elsewhere on the board
/CAN_TXD: J11.10; also elsewhere on the board
/EN: J12.2
/Fuel_Sensor: D4.1 (K), J4.2, J12.15
/GPIO0: J11.14
/GPIO6: J11.19
/GPIO7: J11.18
/GPIO8: J11.17
/GPIO9: J12.16
/GPIO10: J12.17
/GPIO11: J12.18
/GPIO12: J12.13
/GPIO14: J1.3, J12.12
/GPIO15: J11.16
/GPIO26: J1.1, J12.10
/GPIO27: J1.2, J12.11
/GPIO_32: J12.8
/LEFT_HALL: D5.1 (K), J7.4, J12.3
/RIGHT_HALL: D3.1 (K), J7.3, J12.5
/SDCard/CLK: J11.4; also elsewhere on the board
/SDCard/CS: J11.9; also elsewhere on the board
/SDCard/DAT_1: J11.2; also elsewhere on the board
/SDCard/DAT_2: J11.8; also elsewhere on the board
/SDCard/DAT_3: J11.6; also elsewhere on the board
/SDCard/MISO: J11.3; also elsewhere on the board
/SDCard/MOSI: J11.5; also elsewhere on the board
/TEMP_SENSOR: D6.1 (K), J7.2, J12.7
GND: C11.2, D3.2 (A), D4.2 (A), D5.2 (A), D6.2 (A), J1.4, J4.1, J7.1, J11.1, J11.7, J12.14; also elsewhere on the board

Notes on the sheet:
ESP32 DEVKIT

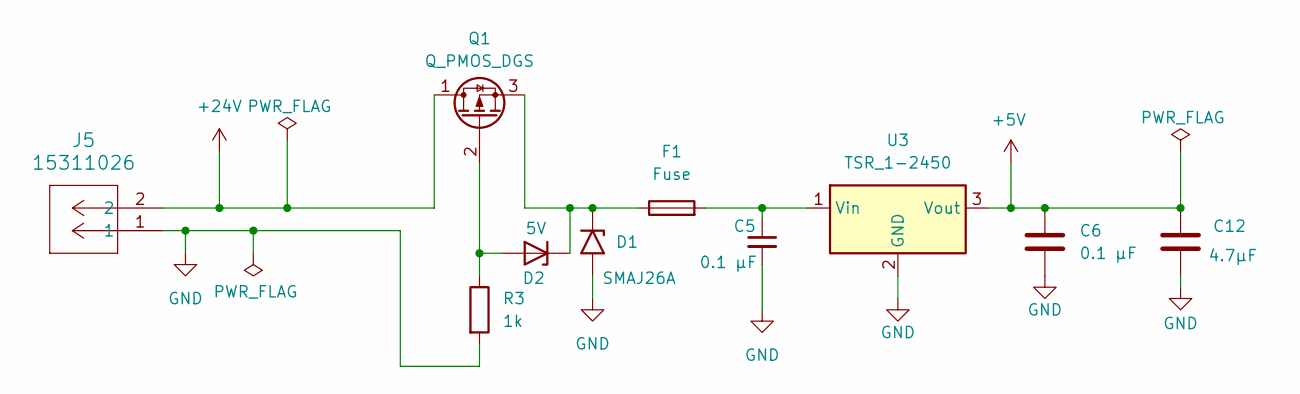
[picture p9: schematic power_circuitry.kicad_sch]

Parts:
C5: 0.1 µF; C_0603_1608Metric_Pad1.08x0.95mm_HandSolder
C6: 0.1 µF; C_0805_2012Metric_Pad1.18x1.45mm_HandSolder
C12: 4.7µF; C_0603_1608Metric_Pad1.08x0.95mm_HandSolder
D1: SMAJ26A; D_SMA
D2: 5V; D_SMA
F1: Fuse; Fuse_0603_1608Metric_Pad1.05x0.95mm_HandSolder
J5: 15311026; MOLEX_15311026
Q1: Q_PMOS_DGS; SOT-23-3
R3: 1k; R_0603_1608Metric_Pad0.98x0.95mm_HandSolder
U3: TSR_1-2450; Converter_DCDC_TRACO_TSR-1_THT

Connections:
+5V: C6.1, C12.1, U3.3 (Vout); also elsewhere on the board
+24V: J5.2, Q1.1 (D)
GND: C5.2, C6.2, C12.2, D1.2 (A2), J5.1, R3.2, U3.2 (GND); also elsewhere on the board
unnamed: D1.1 (A1), D2.1 (K), F1.1, Q1.3 (S)
unnamed: D2.2 (A), Q1.2 (G), R3.1
unnamed: C5.1, F1.2, U3.1 (Vin)

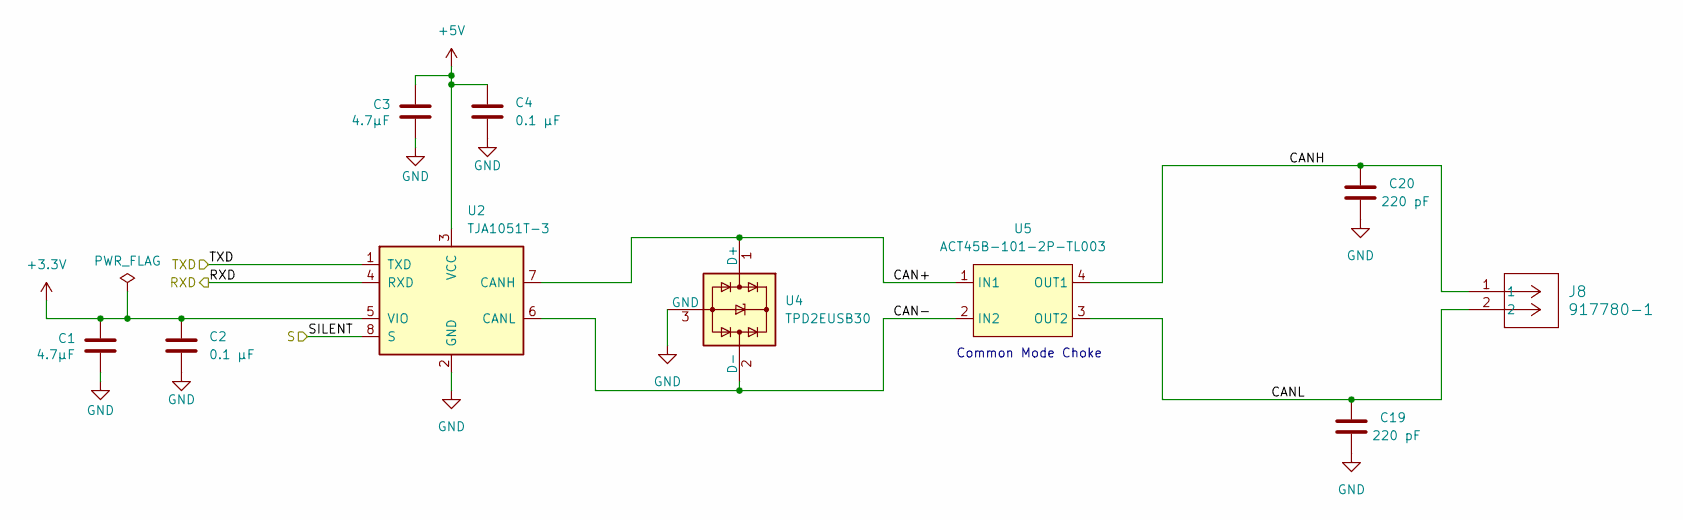
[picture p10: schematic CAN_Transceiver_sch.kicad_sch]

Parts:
C1, C3: 4.7µF; C_0603_1608Metric_Pad1.08x0.95mm_HandSolder
C2, C4: 0.1 µF; C_0805_2012Metric_Pad1.18x1.45mm_HandSolder
C19, C20: 220 pF; C_0603_1608Metric_Pad1.08x0.95mm_HandSolder
J8: 917780-1; CON2_1X2_P100
U2: TJA1051T-3; SOIC-8_3.9x4.9mm_P1.27mm
U4: TPD2EUSB30; Texas_DRT-3
U5: ACT45B-101-2P-TL003

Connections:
+3.3V: C1.1, C2.1, U2.5 (VIO); also elsewhere on the board
+5V: C3.1, C4.1, U2.3 (VCC); also elsewhere on the board
/CAN Transceiver/CAN+: U2.7 (CANH), U4.1 (D+), U5.1 (IN1)
/CAN Transceiver/CAN-: U2.6 (CANL), U4.2 (D-), U5.2 (IN2)
/CAN Transceiver/CANH: C20.1, J8.1, U5.4 (OUT1)
/CAN Transceiver/CANL: C19.1, J8.2, U5.3 (OUT2)
/CAN_RXD: U2.4 (RXD); also elsewhere on the board
/CAN_S: U2.8 (S); also elsewhere on the board
/CAN_TXD: U2.1 (TXD); also elsewhere on the board
GND: C1.2, C2.2, C3.2, C4.2, C19.2, C20.2, U2.2 (GND), U4.3 (GND); also elsewhere on the board

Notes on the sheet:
Common Mode Choke

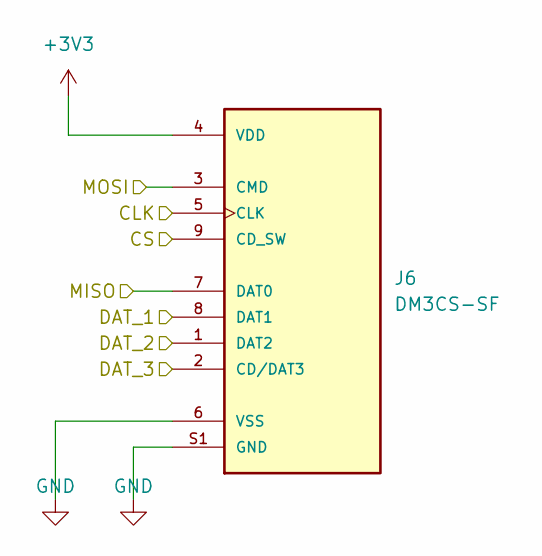
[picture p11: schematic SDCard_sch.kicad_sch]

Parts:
J6: DM3CS-SF; SD_Card; PARTREV n/a

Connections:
+3V3: J6.4 (VDD); also elsewhere on the board
/SDCard/CLK: J6.5 (CLK); also elsewhere on the board
/SDCard/CS: J6.9 (CD_SW); also elsewhere on the board
/SDCard/DAT_1: J6.8 (DAT1); also elsewhere on the board
/SDCard/DAT_2: J6.1 (DAT2); also elsewhere on the board
/SDCard/DAT_3: J6.2 (CD/DAT3); also elsewhere on the board
/SDCard/MISO: J6.7 (DAT0); also elsewhere on the board
/SDCard/MOSI: J6.3 (CMD); also elsewhere on the board
GND: J6.6 (VSS), J6.S1 (GND), J6.S2 (GND), J6.S3 (GND), J6.S5 (GND); also elsewhere on the board

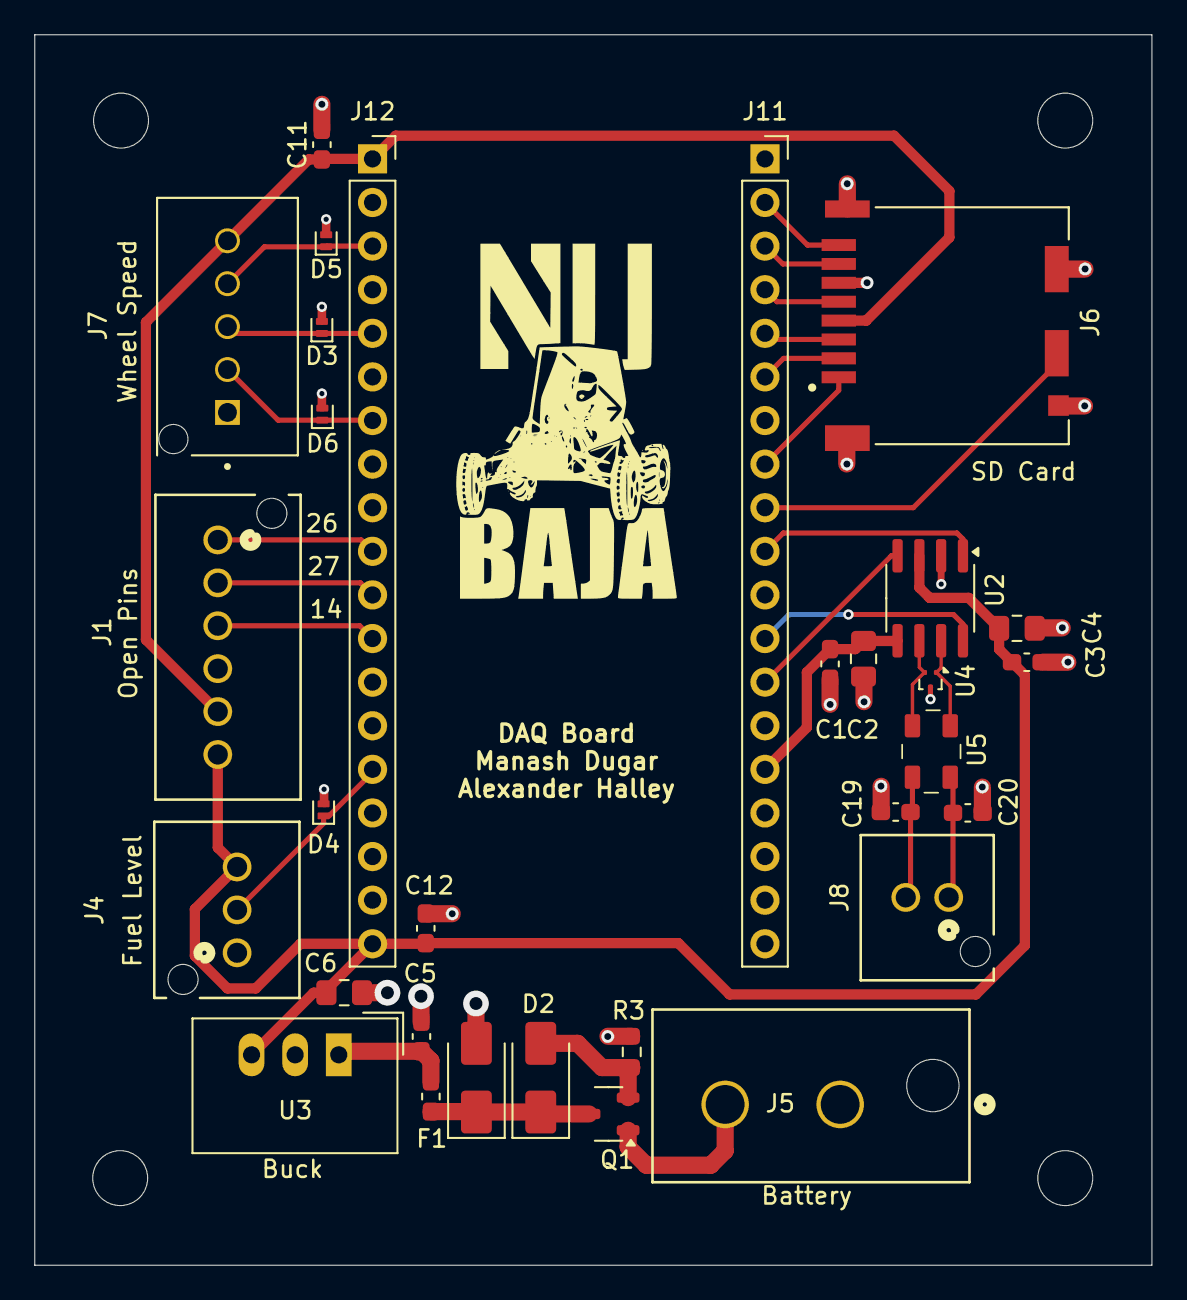
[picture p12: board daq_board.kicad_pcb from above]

Board: 2 copper layers, 65.1 x 71.7 mm, 35 parts (0 on the bottom side), 29 nets.

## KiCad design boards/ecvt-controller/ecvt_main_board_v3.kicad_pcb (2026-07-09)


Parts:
H1, H2, H3, H4: MountingHole; MountingHole_3.2mm_M3


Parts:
C14, C16: 4.7µF; C_0603_1608Metric_Pad1.08x0.95mm_HandSolder
C15, C17, C18: 0.1 µF; C_0603_1608Metric_Pad1.08x0.95mm_HandSolder
C19, C20: 220 pF; C_0603_1608Metric_Pad1.08x0.95mm_HandSolder
R4, R5: 60; R_1206_3216Metric_Pad1.30x1.75mm_HandSolder
U4: TJA1051T-3; SOIC-8_3.9x4.9mm_P1.27mm
U5: ACT45B-101-2P-TL003
U6: ESD3V3AP-TP; SOT-23

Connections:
+3V3: C14.1, C15.1, U4.5 (VIO); also elsewhere on the board
+5V: C16.1, C17.1, U4.3 (VCC); also elsewhere on the board
/CAN Transceiver/BY: C18.1, R4.1, R5.1
/CAN Transceiver/CAN+: U4.7 (CANH), U5.1 (IN1), U6.1
/CAN Transceiver/CAN-: U4.6 (CANL), U5.2 (IN2), U6.2
/CAN Transceiver/CANH: C20.1, R4.2, U5.4 (OUT1); also elsewhere on the board
/CAN Transceiver/CANL: C19.1, R5.2, U5.3 (OUT2); also elsewhere on the board
/CAN Transceiver/RXD: U4.4 (RXD); also elsewhere on the board
/CAN Transceiver/S: U4.8 (S); also elsewhere on the board
/CAN Transceiver/TXD: U4.1 (TXD); also elsewhere on the board
GND: C14.2, C15.2, C16.2, C17.2, C18.2, C19.2, C20.2, U4.2 (GND), U6.3; also elsewhere on the board

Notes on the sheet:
Common Mode Choke


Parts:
C9, C10: 0.1 µF; C_0603_1608Metric_Pad1.08x0.95mm_HandSolder
D2: LED; LED_Luminus_MP-3030-1100_3.0x3.0mm
D4: 5V; D_SMA
D5: SMAJ26A; D_SMA
F1: Fuse; Fuse_0603_1608Metric_Pad1.05x0.95mm_HandSolder
Q1: Q_PMOS_DGS; SOT-23-3
R3: 1k; R_0603_1608Metric_Pad0.98x0.95mm_HandSolder
R7: 10k; R_0603_1608Metric_Pad0.98x0.95mm_HandSolder
U3: TSR_1-2450; Converter_DCDC_TRACO_TSR-1_THT

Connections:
+5V: C10.1, U3.3 (Vout); also elsewhere on the board
+24V: D2.2 (A), Q1.2 (D); also elsewhere on the board
/Motor Driver/24VinReg: D4.1 (K), D5.1 (A1), F1.1, Q1.3 (S); also elsewhere on the board
/Power Circuitry/B_LED: D2.1 (K), R7.1
/Power Circuitry/Buck Input: C9.1, F1.2, U3.1 (Vin)
/Power Circuitry/MOSFET: D4.2 (A), Q1.1 (G), R3.1
GND: C9.2, C10.2, D5.2 (A2), R3.2, R7.2, U3.2 (GND); also elsewhere on the board

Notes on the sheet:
BATTERY
LOAD

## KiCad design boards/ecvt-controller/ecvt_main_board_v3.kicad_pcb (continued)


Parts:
C11, C13: 0.1 µF; C_0603_1608Metric_Pad1.08x0.95mm_HandSolder
C12: 4.7µF; C_0603_1608Metric_Pad1.08x0.95mm_HandSolder
J8, J9: Conn_01x19_Socket; PinSocket_1x19_P2.54mm_Vertical

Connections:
+3V3: C11.1, J8.1; also elsewhere on the board
+5V: C12.1, C13.1, J8.19; also elsewhere on the board
/CAN Transceiver/RXD: J9.13; also elsewhere on the board
/CAN Transceiver/S: J9.8; also elsewhere on the board
/CAN Transceiver/TXD: J9.10; also elsewhere on the board
/Connector Bank/ENCODER_B: J8.6; also elsewhere on the board
/Connector Bank/ENCODER_PWM/A: J8.5; also elsewhere on the board
/Connector Bank/LIN_POT: J8.4; also elsewhere on the board
/Connector Bank/MANUAL_MODE: J8.3; also elsewhere on the board
/Connector Bank/PRIM_RPM: J8.10; also elsewhere on the board
/Connector Bank/SEC_RPM: J8.11; also elsewhere on the board
/Ecvt_MCU/DIR: J8.15; also elsewhere on the board
/Ecvt_MCU/EN: J8.2
/Ecvt_MCU/ENABLE: J8.9; also elsewhere on the board
/Ecvt_MCU/GPIO0: J9.14
/Ecvt_MCU/GPIO1: J9.4
/Ecvt_MCU/GPIO2: J9.15
/Ecvt_MCU/GPIO3: J9.5
/Ecvt_MCU/GPIO6: J9.19
/Ecvt_MCU/GPIO7: J9.18
/Ecvt_MCU/GPIO8: J9.17
/Ecvt_MCU/GPIO9: J8.16
/Ecvt_MCU/GPIO10: J8.17
/Ecvt_MCU/GPIO11: J8.18
/Ecvt_MCU/GPIO12: J8.13
/Ecvt_MCU/GPIO14: J8.12
/Ecvt_MCU/GPIO15: J9.16
/Ecvt_MCU/GPIO32: J8.7
/Ecvt_MCU/SCLK: J9.11; also elsewhere on the board
/Ecvt_MCU/SDI: J9.6; also elsewhere on the board
/Ecvt_MCU/SDO: J9.3; also elsewhere on the board
/Ecvt_MCU/STEP: J9.12; also elsewhere on the board
/Ecvt_MCU/nSCS: J9.2; also elsewhere on the board
/Ecvt_MCU/nSLEEP: J8.8; also elsewhere on the board
GND: C11.2, C12.2, C13.2, J8.14, J9.1, J9.7; also elsewhere on the board

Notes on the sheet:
ESP32 DEVKIT


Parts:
C1, C3, C5: 0.01µF; C_0603_1608Metric_Pad1.08x0.95mm_HandSolder
C2: 100µF; CP_Elec_10x10.5
C4, C7: 1µF; C_0603_1608Metric_Pad1.08x0.95mm_HandSolder
C6, C8: 0.1 µF; C_0603_1608Metric_Pad1.08x0.95mm_HandSolder
R1, R2: 10kΩ; R_0603_1608Metric_Pad0.98x0.95mm_HandSolder
U1: TI DRV8462DDVR; HTSSOP-44_6.1x14mm_P0.635mm_TopEP4.14x7.01mm

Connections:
+5V: C8.1, U1.42 (VCC); also elsewhere on the board
/Connector Bank/A+: U1.17 (AOUT1), U1.18 (AOUT1), U1.19 (AOUT1); also elsewhere on the board
/Connector Bank/A-: U1.14 (AOUT2), U1.15 (AOUT2), U1.16 (AOUT2); also elsewhere on the board
/Connector Bank/B+: U1.7 (BOUT2), U1.8 (BOUT2), U1.9 (BOUT2); also elsewhere on the board
/Connector Bank/B-: U1.4 (BOUT1), U1.5 (BOUT1), U1.6 (BOUT1); also elsewhere on the board
/Ecvt_MCU/DIR: U1.27 (DIR); also elsewhere on the board
/Ecvt_MCU/ENABLE: U1.26 (ENABLE); also elsewhere on the board
/Ecvt_MCU/SCLK: U1.29 (SCLK/M1); also elsewhere on the board
/Ecvt_MCU/SDI: U1.30 (SDI/DECAY0); also elsewhere on the board
/Ecvt_MCU/SDO: U1.31 (SDO/DECAY1); also elsewhere on the board
/Ecvt_MCU/STEP: U1.28 (STEP); also elsewhere on the board
/Ecvt_MCU/nSCS: U1.33 (nSCS/M0); also elsewhere on the board
/Ecvt_MCU/nSLEEP: U1.25 (nSLEEP); also elsewhere on the board
/Motor Driver/24VinReg: C1.1, C2.1, C3.1, C4.2, C5.1, U1.2 (VM), U1.11 (VM), U1.12 (VM), U1.21 (VM); also elsewhere on the board
/Motor Driver/CPH: C6.1, U1.23 (CPH)
/Motor Driver/CPL: C6.2, U1.24 (CPL)
/Motor Driver/DVDD: C7.1, R1.2, R2.2, U1.39 (MODE), U1.43 (DVDD)
/Motor Driver/VCP: C4.1, U1.22 (VCP)
/Motor Driver/nFAULT: R1.1, U1.41 (nFAULT)
/Motor Driver/nHOME: R2.1, U1.40 (nHOME)
GND: C1.2, C2.2, C3.2, C5.2, C7.2, C8.2, U1.1 (GND), U1.3 (PGNDB), U1.10 (PGNDB), U1.13 (PGNDA), U1.20 (PGNDA), U1.34 (VREF), U1.44 (GND); also elsewhere on the board


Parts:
D6: LED; LED_Luminus_MP-3030-1100_3.0x3.0mm
J1: 917782-1; TE-Connectivity_917782
J2: 15311046; MOLEX_15311046
J3: 917784-1; TE-Connectivity_1x6
J4: 15311026; MOLEX_15311026
J5: 917786-1; TE-Connectivity_917786
J6: 917780-1; TE-Connectivity_ 917780
J10: 917781-1; TE-Connectivity_917781
R6: 10k; R_0603_1608Metric_Pad0.98x0.95mm_HandSolder
U2, U7: ESD3V3AP-TP; SOT-23
U8: S23LC03; SOT-23

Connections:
+3V3: J3.1, J3.4, J5.1, J5.4, J10.1; also elsewhere on the board
+5V: J1.1, J1.2, J5.5; also elsewhere on the board
+24V: J4.1; also elsewhere on the board
/CAN Transceiver/CANH: J6.1; also elsewhere on the board
/CAN Transceiver/CANL: J6.2; also elsewhere on the board
/Connector Bank/A+: D6.1 (K), J2.1; also elsewhere on the board
/Connector Bank/A-: J2.2; also elsewhere on the board
/Connector Bank/B+: J2.3; also elsewhere on the board
/Connector Bank/B-: J2.4; also elsewhere on the board
/Connector Bank/ENCODER_B: J5.7, U2.1; also elsewhere on the board
/Connector Bank/ENCODER_PWM/A: J5.6, U2.2; also elsewhere on the board
/Connector Bank/LIN_POT: J5.2, U8.1, U8.2; also elsewhere on the board
/Connector Bank/MANUAL_MODE: J10.2; also elsewhere on the board
/Connector Bank/M_LED: D6.2 (A), R6.2
/Connector Bank/PRIM_RPM: J3.2, U7.2; also elsewhere on the board
/Connector Bank/SEC_RPM: J3.5, U7.1; also elsewhere on the board
GND: J1.3, J1.4, J3.3, J3.6, J4.2, J5.3, J5.8, J10.3, R6.1, U2.3, U7.3, U8.3; also elsewhere on the board

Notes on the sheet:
5V Sockets from Buck Converter
Manual Mode
Motor
50mm stroke, 2kR, linpot w/ rod ends
Motor Encoder
Battery
Sensor Outputs
Can you CANCAN


Board: 4 copper layers, 65.2 x 100.8 mm, 54 parts (1 on the bottom side), 41 nets.

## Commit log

2026-06-30 Scaffold hardware monorepo structure
    [consolidated-bom.csv]
2026-06-30 Fix CI yaml line endings, drop telemetry-node (3 boards only)
    [consolidated-bom.csv]
2026-06-30 Normalize line endings to LF
    [consolidated-bom.csv]
2026-07-01 Expand README with beginner-friendly Git/GitHub/KiCad usage guide
2026-07-06 Add shared baja-common-parts KiCad library and passive/trace-width lint CI
    Curate a shared symbol/footprint library from parts actually used across
    2026 boards, document setup and conventions in libraries/README.md, and
    add CI checks enforcing standard passive footprint sizes and netclass
    trace widths.
2026-07-06 Add minimal KiCad project under hud-node to exercise CI
    RC low-pass filter stub (R1/C1/C2) with correct standard passive
    footprints and netclass trace widths so both lint jobs pass. Opens in
    KiCad; triggers the boards/** CI workflow.
    [hud_node.kicad_pcb, hud_node.kicad_sch]
2026-07-06 Trigger Hardware CI on push to boards/** as well as PRs
    So direct pushes to main that touch a board also run the lint jobs.
2026-07-06 Implement all CI jobs and auto-BOM generation
    - generate_bom.py: real implementation that parses .kicad_sch S-expressions
    directly (stdlib only) and writes bom/consolidated-bom.csv, one line item
    per part per board; handles DNP exclusion, multi-unit symbols, hierarchical
    sheet instances, and MPN/Manufacturer properties; --check mode for CI
    - ci.yml: replace all placeholder jobs with real ones
    - erc-drc: kicad-cli sch erc / pcb drc per board in kicad/kicad:9.0,
    reports uploaded as artifacts
    - render-artifacts: schematic PDFs + front/back PCB layer SVGs
    - bom: --check on PRs (fail if committed CSV is stale) with BOM diff vs
    base in the job summary; auto-commit regenerated C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
    [consolidated-bom.csv, hud_node.kicad_pcb, hud_node.kicad_sch]
2026-07-06 Make container-job CI scripts POSIX sh compatible
    The kicad/kicad:9.0 image has no bash, so GitHub runs container job steps
    with plain sh; shopt/globstar failed with exit 127. Use find instead.
2026-07-09 Add real DAQ/eCVT/Dashboard boards; replace hud-node stub
    Import the three previous-year boards (DAQ_PCB, ecvt_main_board_v3,
    Dashboard) as the DAQ, eCVT, and HUD nodes, cleaned of backup/fab/cache
    junk. Replaces the placeholder hud-node KiCad files with the real Dashboard
    board. Fixes the eCVT sym-lib-table, which pointed at a personal Downloads
    path, to reference the shared baja-common-parts library via ${BAJA_LIB}.
    These carry the off-board harness connectors (TE 917xxx signal + Molex
    15311026/46 power) that the harness pipeline extracts from.
    [CAN_Transceiver.kicad_sch, CAN_Transceiver_sch.kicad_sch, Can.kicad_sch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]
2026-07-09 Add board-driven harness diagram pipeline; rewire CI
    Generate the car's off-board wiring diagram from the KiCad boards on every
    push, so it can't drift out of sync with the schematics.
    - harness/scripts/extract_connectors.py: runs kicad-cli netlist per board,
    keeps only the harness connector families (TE 917xxx, Molex 15311026/46),
    and emits harness/generated/<board>.yaml (one connector per J-ref, each
    pin named by its net). Has --check for CI staleness detection.
    - harness/car.yaml: hand-maintained backbone that includes the generated
    per-board connectors and declares the battery/master-switch spine, the CAN
    bus, and +24V power distribution to all three boards.
    - harness/wirelab/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
2026-07-09 Auto-regenerate consolidated BOM [skip ci]
    [consolidated-bom.csv]
2026-07-09 Fix trace-width null-netclass crash and harness-render pip bootstrap
    Two CI tooling fixes surfaced by importing the real boards:
    - check_trace_widths.py crashed with AttributeError when a .kicad_pro has
    net_settings.netclass_assignments (or classes/patterns) present as an
    explicit JSON null rather than absent -- dict.get(key, default) returns
    None, not the default, for a present-but-null value. Coerce each to its
    empty form before iterating. ecvt/hud boards trip this.
    - harness-render assumed the kicad/kicad:9.0 image ships pip; it doesn't.
    Bootstrap pip via ensurepip (part of CPython) and install only the build
    deps (pydantic, PyYAML) from a new requirements-build.txt -- the ed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
2026-07-09 Allow 1206 passives and exempt bulk caps from footprint lint
    The imported boards were physically built and worked, so the passive
    footprint standard should accept the sizes they actually use:
    - Add 1206 to the allowed chip sizes (0603/0805/1206, HandSolder variant).
    - Exempt bulk/polarized caps (CP_* electrolytic/tantalum families) from the
    chip-size rule entirely -- a bulk energy-storage cap can't be shrunk to a
    chip footprint, so flagging it was a false positive.
    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
2026-07-09 Fix harness-render dep install: apt pip, not ensurepip
    The kicad/kicad:9.0 image has neither pip nor ensurepip (ensurepip is
    stripped; pip comes from apt on this Debian image), so the previous
    ensurepip bootstrap failed with "No module named ensurepip".
    Install deps defensively: skip pip entirely if the bundled Python already
    has pydantic + PyYAML; otherwise apt-install python3-pip and pip-install
    them, trying --break-system-packages first (PEP 668) and falling back to
    plain install for older pip. Ends with an import check that fails clearly if
    anything is still missing.
2026-07-09 Make wirelab serve import lazy so build has no ruamel dependency
    cli.py imported `serve` at module load, which imports yaml_edit ->
    ruamel.yaml. That forced the editor-only dependency onto the build/bom/check
    paths, so `cli.py build` failed in CI with ModuleNotFoundError: ruamel (CI
    installs only the build deps, pydantic + PyYAML).
    Move the `serve` import inside cmd_serve so it's loaded only when the
    interactive editor is actually run. Verified the build path succeeds with
    ruamel unimportable.
2026-07-10 Fix harness-render git failure in kicad container
    The harness-render job runs inside kicad/kicad:9.0 as root while the
    workspace is checked out owned by the runner user, so every git command
    failed with "detected dubious ownership" / "fatal: not in a git
    directory". Mark the workspace as a safe directory after checkout so the
    PR staleness diff and the push-to-main auto-commit both work.
2026-07-10 Add auxiliary boards to harness; fix daq + hud ERC errors (#2)
    * Add auxiliary boards to harness; fix daq + hud ERC errors
    Harness / diagram:
    - Support repeated boards in the car diagram by importing one generated
    YAML under multiple include aliases; the renderer now namespaces each
    component's layout zone by its alias so instances get their own column
    (harness/wirelab/parser.py).
    - Add wheel-hall (x4), fuel-sensor, and ecvt-hall aux boards as
    hand-written placeholder generated/*.yaml, instanced and wired in
    car.yaml (front wheels -> HUD J5, rear -> daq J7, eCVT halls -> ecvt J3,
    fuel -> daq J4). Documented the pattern in harness/README.md.
    - extract_connectors.py now also ident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
    [CAN_Transceiver_sch.kicad_sch, Can.kicad_sch, Connectors.kicad_sch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]
2026-07-26 Add ESP32-DevKitC-V4 to shared library; fix BL99232CH load failure
    Add a proper symbol + footprint for the ESP32-DevKitC-V4 (ESP32-WROOM-32)
    MCU board that the daq/hud/eCVT nodes use — previously each board just
    drew a labeled rectangle with generic pin headers.
    - Symbol: full 38-pin pinout with GPIO alt-functions in the pin names;
    3V3/5V/GND typed as power_in for ERC.
    - Footprint MODULE_ESP32-DevKitC-V4: 2x19 THT 2.54mm headers at 22.86mm
    (0.9") row spacing, rectangular pin-1 pad + silk/fab pin-1 markers.
    Also fix a pre-existing bug that made the whole library fail to load in
    KiCad 9.0.3: the BL99232CH symbol's child-unit names had stray U+200E
    (LEFT-TO-RIGHT MARK) characters prefix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
2026-07-26 Add descriptions/keywords and tidy hidden fields in shared library
    Make parts easier to find in the KiCad symbol chooser and cleaner to view:
    - Fill in Description + ki_keywords for symbols that had empty ones
    (Molex SD sockets, the TE 917xxx headers, the ACT45B CAN connector,
    the ESD3V3AP diode, and the NAU7802 load-cell ADC). No symbols were
    renamed, so existing board references are unaffected.
    - Move the hidden Footprint/Datasheet/Description fields off the (0,0)
    origin to stacked positions below each symbol body, so they no longer
    overlap the symbol when "View -> Show Hidden Fields" is enabled (this
    is the grey Molex/PDF-link text seen in the editor preview).
    Verified with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
2026-07-26 Make ESP32-DevKitC-V4 footprint socketed to match the boards
    The daq/hud/eCVT boards mount the ESP32 as a plug-in module in two
    PinSocket_1x19_P2.54mm_Vertical female sockets spaced 22.86mm (0.9")
    apart, not soldered to bare pads. Rebuild MODULE_ESP32-DevKitC-V4 to
    match: two 1x19 2.54mm vertical socket rows at 22.86mm spacing, 1.7mm
    pads / 1.0mm drill, pin 1 rectangular, with per-row silk boxes. Pads
    stay numbered 1-38 so they map to the ESP32-DevKitC-V4 symbol.
    The boards themselves are left unchanged: their existing two-socket +
    net-label representation is already correct for a socketed module, so
    this only fixes the library footprint to reflect that mounting for
    future boards.
    Verified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
2026-07-26 Add pick-proof passives and signature parts to shared library
    Goal: someone with little KiCad experience can open baja-common-parts and
    place the right part without having to know which stock footprint variant
    to pick.
    Pick-proof passives (stock Device:R/Device:C bodies with the team-standard
    HandSolder footprint already filled in, per the README passive standard):
    R_0603, R_0805, R_1206, C_0603, C_0805
    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
2026-10-22 Power circuitry
2026-10-25 power done
2026-10-25 ADC done
2026-10-25 Capacitors !!!!
2026-10-25 Rough Placement
    no traces, slightly worries about 5V and 3.3V
